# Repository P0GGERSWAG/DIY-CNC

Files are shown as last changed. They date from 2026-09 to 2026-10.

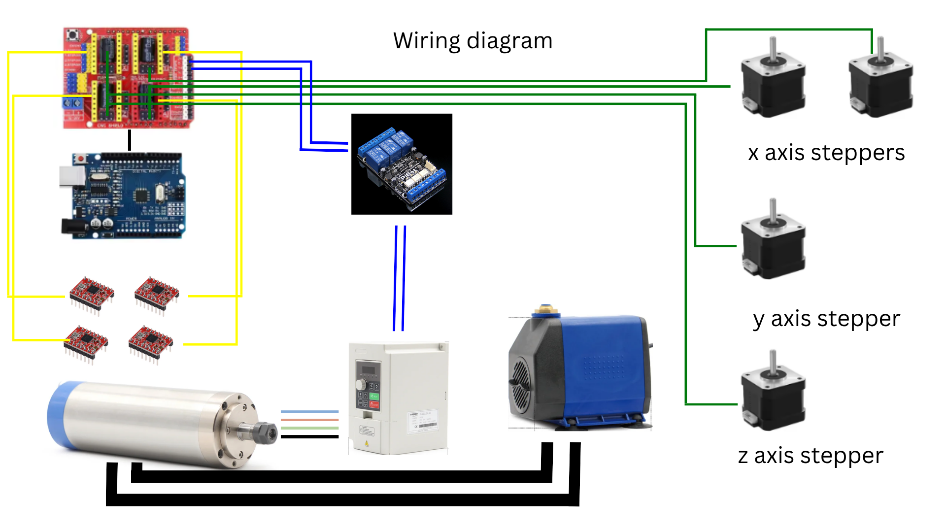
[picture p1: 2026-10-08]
assets/1 (1).png

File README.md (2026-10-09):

# DIY-CNC

This design is my take on the common gantry CNC mill. The design is also more specific toward the US.



## Goal - 
The main focus of the design was to develop a rigid and stable machine that will be able to machine aluminum quickly and harder steels, while also staying relatively cheap. Therefore, the use of 3D printed parts is common as a means to save money on outsourced aluminum machining. Although a majority of the parts are 3D printable it is recommended to later upgrade to aluminum for greater accuracy and rigidity (spindle plates). Other than the spindle, the rest of the build uses aluminum parts that are significantly too big for a standard 256 x 256 x 256 mm 3d printer causing them to have to be outsourced. The reasoning for the sizing of these part (y axis brace and gantry arms) were to cope for significant axial forces. Made this primarily as a design challenge for myself and to use to reduce cost on more complex and expensive machines and devices.

### Reasoning behind build - 
When looking toward the future, I want to design, build, and test more mechanically complex projects and by developing this machine at home I can not only prototype metallic parts quicker, but also save money on shipping and tariffs. I also designed this primarily as a challenge for myself, teaching me more about coreXY, gantrys, and etc.

### CAD - 
The design is essentially complete, with minor changes that are going to be applied once greater testing occurs. 

### Part Selection Reasoning - 
A few of the parts like the 800W water-cooled spindle and the use of SFU1204 ball screws may be questioned, though they were generally chosen to ensure that the parts come nearly 100% safe and simpler to use. Regarding the 800W spindle combo, when researching for a specific spindle I had to consider 3 major things: US power constraints, cooling, and noise. Companies like RATTMOTOR and etc, came up commonly, though when reading each of their reviews they were extremely mixed. Leading me to choose a Chinese company, G-Penny. They sell high quality spindles with solid ceramic bearings and wiring I don't have to tamper with, along with this it simplifies the search, since I needed a VFD that could run 110V. The SFU1204 ball screw was chosen specifically for accuracy, since I plan on making some extremely precise builds in the future and need that accuracy. The use of GRBL and the arduino system was quickly switched to mainly due to the need to reduce cost. The rail selection was based off of sizing and the availability of each on Aliexpress.

## Wiring - 



### Specifications - 

- 290 x 315 x 88 mm working area
- 800W water-cooled spindle
- SFU1204 ball screws for XYZ axis
- Nema 17 open loop steppers
- Concrete-filled base + 2020 extrusion frame

### Firmware/Software - 
GRBL - https://github.com/gnea/grbl/releases#release-v1.1h.20190825

UGS - https://github.com/winder/Universal-G-Code-Sender

### Bill of Materials/Build Instructions - 
https://docs.google.com/document/d/1SkERPSoR8iWG40bx3YqEnEg6MCOHkP-ulHTMdxtHGsY/edit?usp=sharing

Prices may fluctuate from initial values as time passes. It also does not consider taxes and shipping due to the variance.
BOM and total do not include 3d printed parts as it is assumed one already owns a 3d printer. (self funded in my case)

To note, the aluminum parts at the end are for a set of custom milled UPGRADES AND are not required parts, since they can be easily 3d printed, without loosing great rigidity, and use a set of complex geometries.

| Part | Cost | Link | Quantity | Reference Num |
| ---- | ---- | ---- | --- | --- |
| M6 Coupling Nuts | 25.16 | https://www.amazon.com/uxcell-10pcs-M6x10x15mm-Coupling-Nuts/dp/B0F6N7XLS5/ref=sr_1_12 | 4 | 1 |
| Zinc-Plated Steel Coupling Nut Low Strength, 3/8"-16 Thread Size, 1-1/8" Long | 16.50 | https://www.mcmaster.com/90264A113/ | 25 | 2 |
| M4 10mm Coupling Nuts | 6.89 | https://www.amazon.com/MECCANIXITY-Coupling-M4x0-7mm-Connector-Hardware/dp/B0DK9B5V27/ref=sr_1_6 | 1 | 3 |
| Assortment of Screws : Mcmaster - M6 50mm socket head cap M6 30mm socket head cap M6 20mm socket head cap Aliexpress - M5 30mm socket head cap M5 20mm socket head cap M5 10mm socket head cap M4 15mm socket head cap M3 20mm socket head cap M3 15mm socket head cap M3 10mm socket head cap M3 8mm socket head cap m5 30mm roundhead aliexpress | 75.87 | https://www.aliexpress.us/item/3256809207500690.html https://www.aliexpress.us/item/3256806812715286.html https://www.mcmaster.com/91290A326/ https://www.mcmaster.com/91290A205/ https://www.mcmaster.com/91290A332/ | 1 of each | 4 |
| M3 T Nuts | 4.99 | https://www.amazon.com/HELIFOUNER-Pieces-2020-Aluminum-Profile/dp/B0B1LTNX7F/ref=sr_1_3 | 1 | 5 |
| Threaded rods 400mm | 14.93 | https://www.homedepot.com/p/Everbilt-3-8-in-x-6-ft-Zinc-Plated-Steel-Coarse-Threaded-Rod-23031/332734180 | 1 2ft 1 6ft | 6 |
| Limit Switches | 10.99 | https://www.amazon.com/REIFENG-Mechanical-Endstop-Horizontal-Ramps1-4/dp/B07PCN6T6F/ref=sr_1_4 | 1 | 7 |
| Nema17 Stepper Motor KIT + CNC Shield V3 Engraving Machine + A4988 Driver + 42 Stepper Motor Nema17 17Hs4401S With Wire | 53.51 | https://www.aliexpress.us/item/3256804512478212.html | 1 | 8 |
| 24V DC power supply | 6.07 | https://www.amazon.com/Power-Supply-Adapter-Wall-Converter/dp/B0CNLR8ZYB/ref=sr_1_3 | 1 | 9 |
| G-penny 800W 110V spindle + VFD + pump + clamp | 288.00 | https://gpennymachine.com/products/g-penny-0-8kw-er11-d65-220v-400hz-24000rpm-water-cooled-spinle-motor-with-inverter-bracket-water-pump-kit | 1 | 10 |
| Random bag of quick set concrete | 6.27 | https://www.lowes.com/pd/Sakrete-50-lb-Fast-Setting-Concrete-Mix/3338802?store_code=1921 | 1 | 11 |
| MGN12H rail and carriage 500mm 400mm | 132.58 | https://www.aliexpress.us/item/3256809265975522.html | 2 of each | 12 |
| SFU 1204 ball screw 500mm 400mm | 131.06 | https://www.amazon.com/dp/B0B7RM9ZNH/ref=twister_B0CN99BC2K?_encoding=UTF8&th=1 https://www.amazon.com/dp/B09BR414X7/ref=twister_B0CN99BC2K?_encoding=UTF8&th=1 | 2 500mm 1 400mm | 13 |
| SFU 1204 ball screw w/ HGR 20CA rail and carriage 200mm | 54.99 | https://www.amazon.com/dp/B0CW9CVH1V/ref=twister_B0CW8Y79VN?_encoding=UTF8&th=1 | 1 | 14 |
| 2020 Extruded Aluminum: 400mm 500mm 560mm | 105.28 | https://www.aliexpress.us/item/3256807923095651.html | 1 400mm 2 500mm 2 560mm | 15 |
| Frame rails and y axis brace | 242.20 | https://jlccnc.com/ | 2 frame rails 1 axis brace | 16 |
| MDF spoilboard | 4.82 | https://www.homedepot.com/p/ProWood-1-4-in-x-12-in-x-18-in-Medium-Density-Fiberboard-Project-Panel-420510/313763530 | 1 | 17 |
| Relay | 9.99 | https://www.pibot.com/pibot-isolated-relay-rev-2-0.html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 | 1 | 18 |
| Aluminum parts (POTENTIAL UPGRADES IS NOT CONSIDERED IN TOTAL) | 242.20 (FOR FUTURE NOT MADE YET) | https://www.midweststeelsupply.com/store/6061aluminumplate | 3 of 15x5.5 2 of 12.5x4 | 19 |

| Total | 1185.08 |
| ----- | --- |

### Future - 
This github repo will be updated later with full build instructions and improvements to it, once the build is actually built and parts are ordered. 
Due to tariffs and other financial circumstances, the build model may change to cope.

Build Instructions are due to be added once parts are ordered and the build is built.

Submitted on Stardance for funding.

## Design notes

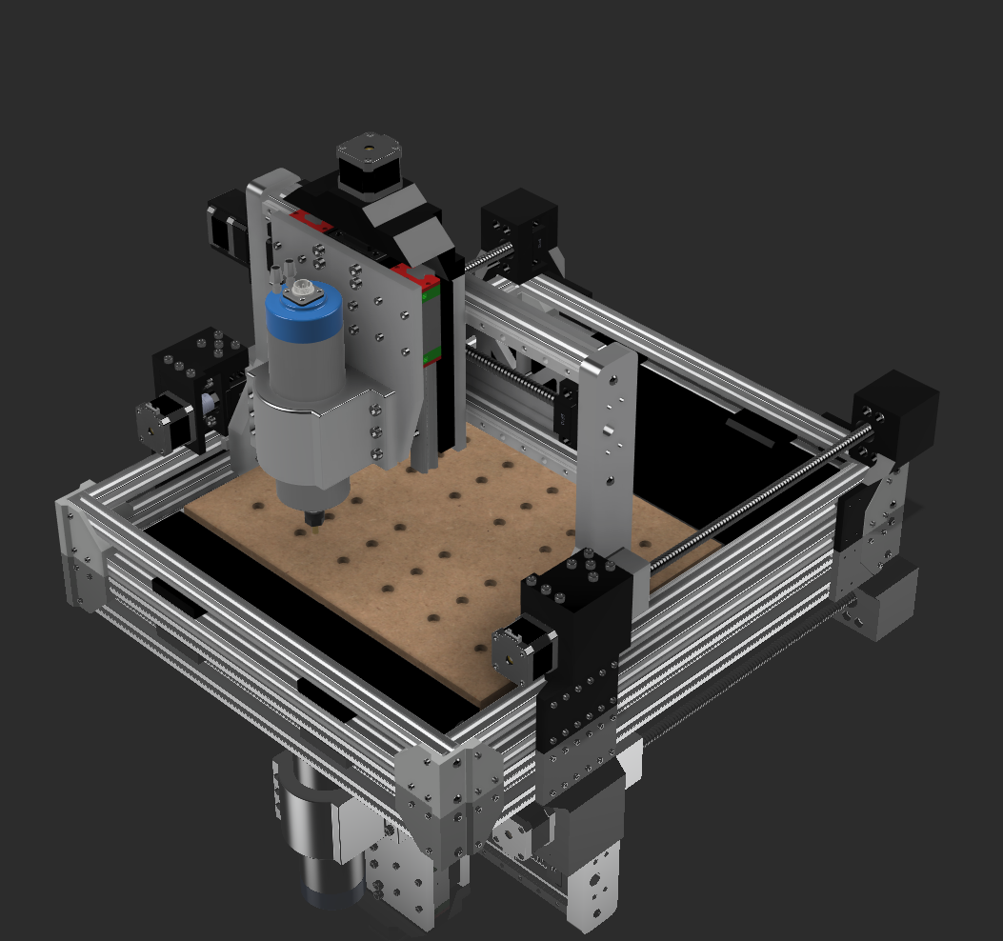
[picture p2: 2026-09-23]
assets/655004650-31d0adc3-f3d0-4f1f-9ee7-5100f57f698c.png

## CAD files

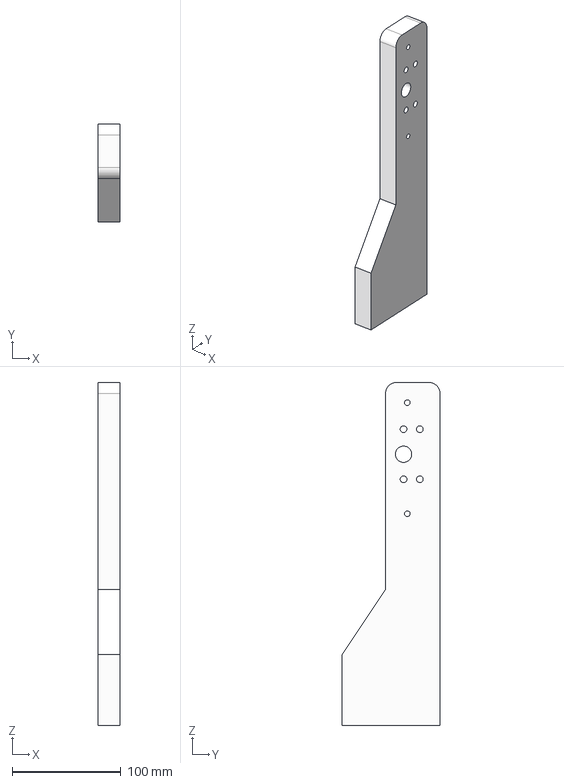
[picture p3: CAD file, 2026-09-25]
CAD/right frame piece.step
20.0 x 90.0 x 315.0 mm

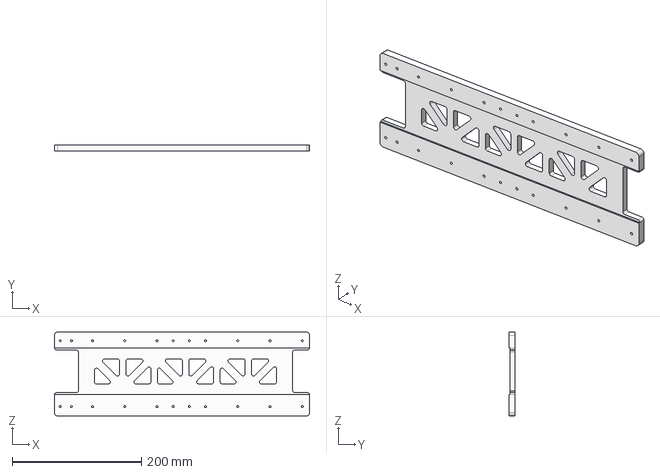
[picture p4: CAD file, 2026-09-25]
CAD/y axis brace.step
395.0 x 10.0 x 130.0 mm

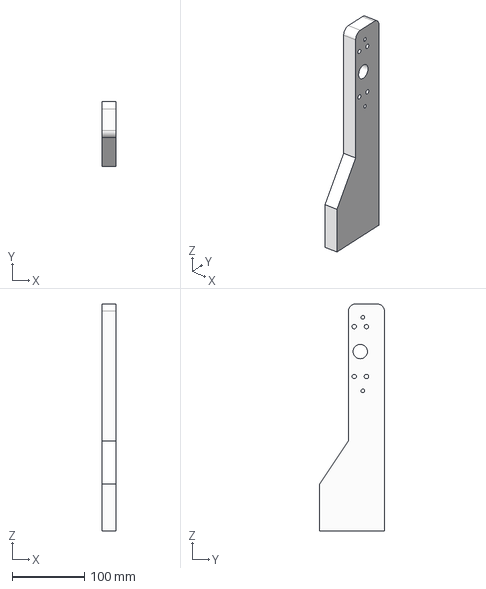
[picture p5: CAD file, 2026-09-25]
CAD/left frame piece.step
20.0 x 90.0 x 315.0 mm

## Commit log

2026-09-19 Update README with Bill of Materials and build notes
    Added link to Bill of Materials and noted that build instructions will be added later.
2026-09-19 Update README with CAD model details and BOM
    Added notes about CAD model and parts used in the build.
2026-09-19 Update README with base material details
    Added information about base material and construction methods.
2026-09-23 Change image source in README
    Updated image source for the CNC mill design.
2026-09-24 Revise README with detailed project information
    Updated the README to include sections on goals, CAD, part selection, specifications, firmware/software, bill of materials, and future plans.
2026-09-24 Revise Bill of Materials with detailed parts list
    Updated the Bill of Materials section with detailed parts, costs, and links. Added notes on price fluctuations and future updates.
2026-09-24 Revise BOM.csv with updated parts and pricing
    Updated BOM.csv to reflect changes in parts, costs, and links.
    [BOM.csv]
2026-09-25 Update note on aluminum parts in README
    Clarified that aluminum parts are optional and can be 3D printed.
2026-09-25 Update BOM.csv with new parts and prices
    [BOM.csv]
2026-09-25 Fix grammatical error in BOM section
    Correct grammatical error in README regarding ownership of 3D printer.
2026-10-08 added relay to bom
2026-10-08 added relay to csv
    [BOM.csv]
2026-10-08 bom column fix
    [BOM.csv]
2026-10-08 Expand README with build reasoning and project goals
    Added reasoning behind the build and goals for the CNC mill design.
2026-10-08 Update README with wiring images and specifications
    Added images and specifications to the README.
